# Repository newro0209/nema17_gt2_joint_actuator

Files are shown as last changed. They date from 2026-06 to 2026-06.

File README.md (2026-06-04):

# NEMA17 (SF2424) GT2 Robot Joint Actuator — 3:1

GT2 타이밍 벨트 감속(20T → **60T = 3:1**) 로봇 조인트 액추에이터.
구조 파트(풀리·샤프트·플레이트)는 **3D 프린팅**, **608ZZ 베어링**과 **GT2 벨트는 구매 부품**으로 처음부터 적용하는 파라메트릭 OpenSCAD 설계입니다.

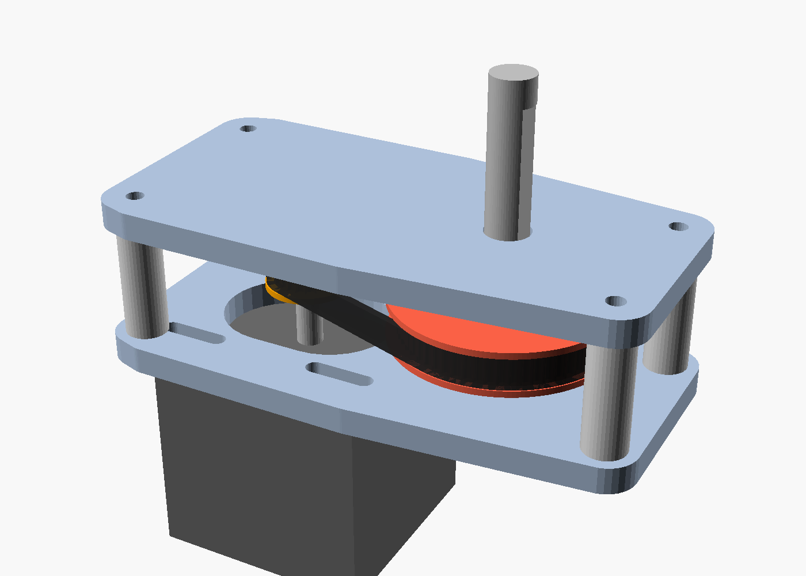
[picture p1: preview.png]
preview


---

## 입력 규격 해석

| 코드 | 해석 |
|---|---|
| `TP-5-6M-20T-16H` (입력 풀리) | Timing Pulley / 보어 **5mm**(NEMA17 샤프트) / 벨트폭 **6mm** / **20T** / 플랜지 OD **16mm** |
| `60T 5MM 8MM` (출력 풀리) | **60T** / 6mm 계열 / 보어 **8mm** |

> **"6M" 해석 (확정):** `6M`을 HTD-6M(6mm 피치)이 아니라 **6mm 벨트폭**으로 해석했고,
> 이 해석이 맞는 것으로 확정되었습니다. **GT2(2mm 피치)** 로 설계했으며, 위 모든 치수(5mm/8mm 보어, 16mm 플랜지)가 GT2 6mm 기준과 일관됩니다.

---

## Repository layout

```text
cad/                 OpenSCAD mechanical design
  lib/               params.scad + reusable modules
  src/               one printable part per file, plus preview-only assembly.scad
  render.ps1         export printable parts to cad/build/*.stl
docs/                reference notes
preview.png          assembly render preview
```

모든 공유 치수와 공차는 **`cad/lib/params.scad`** 에서 관리합니다.
파트별 STL은 `cad/src/*.scad`가 각각 자기 자신을 렌더링하도록 구성되어 있습니다.

---

## 파트 목록

| 파일 | 설명 | 수량 |
|---|---|---|
| `cad/src/input_pulley.scad` | 20T GT2 풀리 (보어 5mm, 플랜지 양면, M3 셋스크류) | 1 |
| `cad/src/output_pulley.scad`  | 60T GT2 풀리 (보어 8mm, 플랜지 양면, M3 셋스크류) | 1 |
| `cad/src/motor_plate.scad` | **모터 패드 + 베어링 허브 트러스 + 4개 코너 타워 일체형**. 모터 구멍은 장력조절용 슬롯 | 1 |
| `cad/src/support_plate.scad`  | 베어링 허브와 4개 체결부를 연결하는 상부 지지 플레이트 | 1 |
| `cad/src/output_shaft.scad` | 프린트 출력샤프트 8mm (셋스크류용 D컷, 샤프트 숄더 일체) | 1 |
| `cad/src/output_arm.scad` | 출력 링크/암 (선택) | 1 |
| `cad/src/assembly.scad` | 전체 조립 시각화 (출력 비대상) | — |

---

## 베어링

출력 구멍에는 **608ZZ 베어링(22 OD × 7 W × 8 ID) 압입 보어**를 사용합니다.
프린트 풀리 + 프린트 8mm 샤프트로 시작하고, 이후 8mm 연삭 샤프트로 교체할 수 있습니다. 프레임/볼트 패턴은 동일합니다.

> **벨트는 구매 부품입니다.** 실물 GT2 6mm 닫힌루프 벨트를 사용하세요(프린팅하지 않음).

### 베어링·샤프트 이탈 방지

`plate_th = bearing_w`로 맞춰 플레이트 자체가 베어링 전체 폭을 지지합니다. 별도의 국소 허브 돌출 없이 압입 보어가 플레이트 전체 두께를 관통합니다.

**베어링 고정: 압입 보어만 사용**

- **압입:** 608ZZ 외륜을 포켓에 압입(`bearing_press_fit = 0.10mm` 간섭) — 라디얼 고정 + 마찰로 축방향도 잡힘
- **포켓:** 외측 립/막힌 캡/내륜 도피 홈 없음. 양 플레이트 모두 Ø`bearing_od - bearing_press_fit` 보어가 베어링 폭만큼 뚫립니다.
- 양 플레이트 외륜은 모두 고정해도 되지만, 내륜은 샤프트 숄더가 한쪽만 잡아 **과구속(바인딩) 없음**

**샤프트 축방향 잠금:**

- `output_shaft` 일체형 **안쪽 숄더** (`shaft_shoulder_d ≈ 12mm`, `shaft_shoulder_h ≈ 3mm`) — 상부 베어링 **갭쪽(안쪽) 내륜 면**에 착좌해 **빠짐(pull-out) 기계적 정지**. 모터 쪽으로 밀림은 출력 풀리 D컷 셋스크류가 잡음. (출력 풀리는 **허브가 아래**로 가게 조립해 이 숄더를 피함)

| 파라미터 | 값 | 설명 |
| --- | --- | ---- |
| `bearing_press_fit` | 0.10 mm | 외륜 압입 간섭(직경) |
| `bearing_od` | 22.0 mm | 608ZZ 외륜 직경 |
| `bearing_w` | 7.0 mm | 608ZZ 폭 및 포켓 깊이 |
| `shaft_shoulder_d` | ~12 mm | 샤프트 숄더 직경 |
| `shaft_shoulder_h` | ~3 mm | 샤프트 숄더 높이 |

---

## 핵심 치수 / 기본값

- 감속비 3:1, 중심거리 `center_distance = 32.5 mm`
- 풀리 PD: 20T ≈ 12.73mm (OD 12.2), 60T ≈ 38.20mm (OD 38.2)
- 벨트: **GT2 6mm 닫힌루프 75T(150mm)**, 플레이트 간격 `plate_gap = 25mm`
- 베어링: 608ZZ ×2 / 출력 보어 8mm / 입력 보어 5mm
- 셋스크류: M3 / **리드↔포스트 결합: M3 자가탭(또는 heat-set 인서트)**
- **스탠드오프 = 모터 플레이트 일체형 코너 타워**: 높이 `plate_gap`, 포스트 상단 `post_pilot_d = 2.6mm` 자가탭 파일럿
- **프레임**: 두 플레이트는 노드(베어링 허브·포스트 보스·모터 패드) + 스트럿 구조입니다. 두 플레이트 형상은 **서로 다르며**, 베이스는 모터 패드와 코너 타워가 한 덩어리처럼 이어집니다. 튜닝: `strut_w = 8`, `hub_collar = 6`, `boss_extra = 3`, `motor_pad_margin = 3`

### 공차 / 끼워맞춤 (0.28mm Standard @ SparkX i7, 0.4 노즐 기준)

빡빡한 출력 프로파일에 맞춰 조이는 값으로 파라미터화:

- `boolean_eps = 0.02` — CSG 겹침 전용(작게 유지, 동일평면 면 방지)
- `bore_clearance = 0.20` — 프린트 보어↔샤프트/스크류 슬립핏(직경)
- `tooth_clearance = 0.06` — GT2 톱니 골 확장(벨트 맞물림)
- `bearing_press_fit = 0.10` — 608ZZ 포켓 압입(양수값은 포켓 직경을 줄임)
- `print_chamfer = 0.6` — 베어링 포켓·풀리 보어·샤프트 끝·암 보어에 45° 리드인(압입/슬립핏 시작 용이 + 첫 레이어 엘리펀트풋 완화)
> 실측 후 너무 빡빡하면 위 값을 0.05~0.1mm씩 키우세요.

### 벨트 길이 / 장력
모터 플레이트의 4개 장착 구멍과 보스 구멍이 **X축 슬롯(`tension_travel = 6mm`)** 이라 모터를 밀고당겨 장력을 잡습니다.

닫힌 루프 벨트 길이:  `L = 2C + π·(PD₁+PD₂)/2 + (PD₂−PD₁)²/(4C)`
- C=32.5 → L ≈ 150mm → **GT2 6mm 닫힌루프 75T(150mm)** 사용 후 슬롯으로 텐션.
- 다른 벨트를 쓰려면 위 식으로 C를 역산해 `center_distance`만 바꾸면 됩니다.

---

## BOM

**프린트**
- input_pulley ×1, output_pulley ×1, **motor_plate ×1 (포스트 일체형)**, support_plate ×1
- output_shaft ×1 (숄더 일체), (선택) output_arm ×1

**하드웨어 (구매, 필수)**

- **608ZZ 베어링 ×2** (22 OD × 8 ID × 7 W)  ← 처음부터 적용 (압입 보어만 사용)
- **GT2 6mm 닫힌루프 벨트 75T(150mm) ×1**  ← 직접 구매
- M3 grub(셋스크류) ×2 (풀리 ×2), 가능하면 황동 heat-set 인서트
- **리드↔포스트 M3 스크류 ×4** — 자가탭이면 M3×18~20, 길이 ≈ `plate_th + post_pilot_depth`(≈ 21mm) 이하. 반복 분해 시 포스트 상단에 M3 heat-set 인서트 권장
- NEMA17 장착 M3 볼트 ×4
- _별도 스페이서·너트·긴 관통볼트는 일체형 포스트로 제거됨_

**업그레이드 (선택)**
- Ø8 h7 연삭 샤프트 ×1 (길이 ≈ **77mm**) — 프린트 출력샤프트 대체. 연삭 샤프트는 일체형 숄더가 없으므로 상부도 칼라/E-클립으로 구속하세요.

---

## 프린트 권장

- 프로파일: **0.28mm Standard @ SparkX i7 (0.4 노즐)** 기준. 풀리 톱니 정밀도가 더 필요하면 0.16mm로 낮춤
- 벽 3 perimeter, 인필 ≥ 40%
- **motor_plate(베이스): 모터 면을 베드에 바닥으로 → 포스트가 위로** 수직 출력, 서포트 불필요. 포스트·베어링 포켓·파일럿 모두 위로 열려 브리징 없음
- **두 플레이트는 베어링 폭과 같은 7mm 두께**입니다. 별도 허브 돌출이 없고, 압입 보어가 플레이트 전체 두께를 관통합니다.
  - 베이스(motor_plate): **포켓이 위로**(모터 면이 베드). 보어가 위로 열려 브리징 없음.
  - 리드(support_plate): **플레이트가 베드에 평평**. 단순 관통 보어라 립 브리징 없음.
- 스트럿이 너무 약하면 `strut_w`를 키우고, 더 가볍게 하려면 줄이세요(강성 ↔ 필라멘트 트레이드오프)
- 풀리: 플랜지면을 베드 바닥으로(현재 모델 방향 그대로). 서포트 불필요
- **output_shaft: 모터단(짧은 쪽)을 베드로 향하게 수직 출력(motor-end-down).** 안쪽 숄더의 시트면이 위를 향해 평평한 선반이 되고, 숄더 아랫면 45° 원뿔이 유일한 아래보기 면이라 서포트 없이 출력됩니다.
- 공차는 `tooth_clearance`/`bore_clearance`/`bearing_press_fit`로 튜닝(위 _공차/끼워맞춤_ 참고)
- **45° 리드인 모따기**(`print_chamfer`)가 베어링 포켓·풀리 보어·샤프트 끝·암 보어에 적용되어 압입/슬립핏 조립이 자동 정렬되고 베드 면 엘리펀트풋을 흡수합니다. 첫 레이어가 부풀어 빡빡하면 값을 키우세요.
- 리드↔포스트 체결: 포스트 파일럿에 M3 자가탭, 또는 상단에 M3 heat-set 인서트
- **일체형 포스트 = 별도 파트 4개 제거 → 출력 셋업·필라멘트·시간 절감**

---

## 조립 순서

1. **608ZZ 베어링 압입:** 양 플레이트의 압입 보어에 608ZZ를 수직으로 눌러 끼웁니다. 플레이트 면과 베어링 외측 면이 맞으면 완전히 착좌된 것입니다. 무리한 타격 금지 — 손으로 누르거나 프린트 지그로 균등하게 압입하세요.
2. motor_plate(포스트 일체형)에 NEMA17 장착(슬롯에 느슨하게) → 입력 풀리 모터축 고정.
3. **output_shaft를 갭 쪽에서 motor_plate(하부) 베어링에 통과**시켜 아래로 내립니다(안쪽 숄더가 갭 상단에 위치). output_pulley를 **허브가 아래로 향하게** 갭 안에서 샤프트에 끼우고 셋스크류 임시 고정.
4. 벨트를 두 풀리에 건다.
5. **support_plate(리드)를 샤프트 위에서 4개 포스트에 얹습니다.** 리드의 상부 베어링이 샤프트를 따라 내려오다 **샤프트 숄더에 착좌**합니다. M3 스크류로 리드↔포스트 체결(자가탭/인서트). → 숄더가 상부 베어링 내륜에 착좌해 샤프트 축방향을 구속합니다.
7. 두 풀리의 **톱니 중앙 평면을 일치**시키고 output_pulley 셋스크류 최종 체결 (벨트 정렬의 핵심).
8. 모터를 슬롯에서 밀어 장력 조절 후 NEMA17 볼트 조임.

---

## 재현 / 내보내기

```powershell
.\cad\render.ps1                  # 모든 출력 파트 -> cad\build\*.stl
.\cad\render.ps1 motor_plate      # 단일 파트만 출력
```

수동 출력 예시:

```powershell
$osc = "C:\Program Files\OpenSCAD\openscad.exe"
& $osc -o cad\build\motor_plate.stl --export-format binstl cad\src\motor_plate.scad
```

전 파트 OpenSCAD에서 manifold·NoError 검증 완료.

---

## 알려진 가정 / 다음 단계

- NEMA17 **샤프트 5mm, 보스 22mm, 볼트피치 31mm** 표준 가정. `motor_body_len`(SF2424 몸체 길이)은 실측 권장.
- 프레임 플레이트는 견고하지만 무겁습니다 — 동작 검증 후 경량화(포켓/리브) 추천.

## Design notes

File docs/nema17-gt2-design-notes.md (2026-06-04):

# NEMA17 GT2 Joint Actuator Design Notes
(NEMA17 GT2 조인트 액추에이터 설계 노트)

## Current Defaults
(현재 기본 설정)

- Reduction: 3:1 using 20T input and 60T output GT2 pulleys.
  (감속비: 20T 입력 및 60T 출력 GT2 풀리를 사용한 3:1 감속.)
- Belt: GT2, 6 mm wide, 150 mm closed loop.
  (벨트: GT2, 폭 6mm, 150mm 폐루프.)
- Bearings: two 608ZZ bearings, 22 OD x 8 ID x 7 W.
  (베어링: 608ZZ 베어링 2개, 외경(OD) 22 x 내경(ID) 8 x 폭(W) 7.)
- Output shaft: 8 mm nominal.
  (출력 축: 공칭 8mm.)

## Fit Notes
(조립 공차 노트)

- `bearing_press_fit` is diametral interference. A positive value makes the pocket smaller.
  (`bearing_press_fit`은 직경의 억지 끼워맞춤 정도를 나타냅니다. 양수 값은 포켓을 더 작게 만듭니다.)
- Bearing retention is press-fit only; there is no outer lip, blind cap, or inner-race relief feature.
  (베어링 고정은 억지 끼워맞춤만 사용합니다. 외부 립, 막힌 캡, 내륜 도피 홈은 없습니다.)
- Test bearing pockets before printing the full frame if the printer/material has not been characterized.
  (프린터나 재료의 특성이 완전히 파악되지 않았다면, 전체 프레임을 출력하기 전에 베어링 포켓을 먼저 테스트하세요.)

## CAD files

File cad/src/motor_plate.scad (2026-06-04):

include <../lib/params.scad>
include <../lib/util.scad>
include <../lib/gt2.scad>
include <../lib/plates.scad>

motor_plate();

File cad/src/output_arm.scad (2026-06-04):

include <../lib/params.scad>
include <../lib/util.scad>
include <../lib/parts.scad>

output_arm();

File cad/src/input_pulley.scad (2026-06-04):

include <../lib/params.scad>
include <../lib/util.scad>
include <../lib/gt2.scad>

input_pulley();

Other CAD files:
cad/src/assembly.scad
cad/src/output_pulley.scad
cad/src/output_shaft.scad
cad/src/support_plate.scad

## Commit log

2026-06-04 Update README and SCAD files for clarity and accuracy in actuator specifications
    [joint_actuator.scad]
2026-06-04 Refactor project structure and enhance documentation for NEMA17 GT2 actuator
    - Updated .gitignore to exclude cad/build/ directory
    - Revised README.md for improved clarity on repository layout and usage
    - Added CLAUDE.md for detailed project overview and design rules
    - Implemented render.ps1 script for exporting OpenSCAD parts
    - Created assembly.scad and individual part files for modular design
    - Introduced design notes in nema17-gt2-design-notes.md for current defaults and fit notes
    [assembly.scad, input_pulley.scad, joint_actuator.scad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]
2026-06-04 Add new parts and visualization for NEMA17 GT2 Joint Actuator
    - Introduced `parts.scad` containing output shaft and arm modules.
    - Added `plates.scad` for frame plates with output bearing features.
    - Created `util.scad` for generic primitives used across parts.
    - Developed `viz.scad` for assembly visualization including motor, belt, and bearings.
    - Updated `render.ps1` script to improve part rendering process.
    - Removed legacy files: `output_bushing.scad`, `output_collar.scad`, `spacer.scad`, and `joint_actuator.scad`.
    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
    [joint_actuator.scad, output_bushing.scad, output_collar.scad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]
2026-06-04 Refactor bearing retention details and parameters for clarity in design notes and SCAD files
2026-06-04 Refactor bearing support details in README and SCAD files for improved clarity and consistency
2026-06-04 Enhance output shaft design with improved shoulder retention and chamfer features for better assembly and fit
2026-06-05 Fix motor boss diameter to ensure proper fit for SF2424 motor with correct clearance
